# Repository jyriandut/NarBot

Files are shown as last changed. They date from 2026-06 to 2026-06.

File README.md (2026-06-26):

# NarBot

NarBot is an experimental SMARS-style robot workspace. It currently contains
PlatformIO firmware for ESP32 camera/control nodes plus a KiCad PCB project.

The active firmware work is focused on getting reliable ESP32 camera streams,
basic Wi-Fi setup, and simple robot-control building blocks working before
adding a larger autonomous control stack.

## Projects

### `NarbotESP`

Minimal dual-camera firmware for two Seeed Studio XIAO ESP32S3 Sense boards.
The same codebase builds in two modes:

- `main_esp`: starts the `SMARS_MAIN` access point at `192.168.4.1`, serves the
  dashboard, and streams its local camera.
- `front_esp`: joins `SMARS_MAIN` as a station, tries to use static IP
  `192.168.4.10`, and serves its own camera stream.

Main endpoints:

- `http://192.168.4.1/` - dashboard hosted by the main ESP
- `/status` - JSON status
- `/jpg` - single JPEG frame
- `/stream` - MJPEG stream

Default Wi-Fi credentials used by the prototype:

- SSID: `SMARS_MAIN`
- Password: `smars1234`

Build and upload:

```sh
cd NarbotESP
make compile
make upload_main
make upload_front
make monitor
```

Equivalent PlatformIO commands:

```sh
pio run -e main_esp -t upload
pio run -e front_esp -t upload
pio device monitor
```

### `CameraDriver`

Experimental all-in-one XIAO ESP32S3 Sense firmware. This project currently
contains motor-control, camera capture/streaming, setup AP, simple web UI,
serial console, headlight/status LED behavior, and color-sensor code.

Hardware assumptions in the current firmware include:

- Seeed Studio XIAO ESP32S3 Sense with camera
- DFRobot TB6612FNG motor driver
- TCS34725-compatible color sensor at I2C address `0x29`

Setup AP used by the prototype:

- SSID: `CameraDriver-Setup`
- Password: `smars1234`

Build and upload:

```sh
cd CameraDriver
make compile
make upload
make monitor
```

### `NarbotPCB`

KiCad PCB project for the robot electronics.

Commit these files:

- `*.kicad_pro`
- `*.kicad_sch`
- `*.kicad_pcb`

Local KiCad backups and project-local state are ignored by
`NarbotPCB/.gitignore`.

### `ColorCalibration`

Placeholder/calibration workspace. At the moment only generated PlatformIO
output was present, so `.pio/` is ignored there.

## Repository Layout

```text
.
├── CameraDriver/      # Experimental ESP32 camera + motor driver firmware
├── ColorCalibration/  # Calibration workspace
├── NarbotESP/         # Two-ESP camera streaming firmware
├── NarbotPCB/         # KiCad board project
└── README.md
```

## Requirements

- PlatformIO CLI (`pio`)
- USB serial access to the ESP32 boards
- KiCad for the PCB project

The firmware targets ESP32 boards through PlatformIO's `espressif32` platform
and uses the Arduino framework.

## Git Notes

Each project has its own `.gitignore` for generated files. Build output,
downloaded PlatformIO dependencies, clangd caches, notebook scratch files,
macOS metadata, and KiCad backups should stay uncommitted.

Useful status check:

```sh
git status --short --untracked-files=all
```

## Current Milestone

The main firmware milestone is:

1. Main ESP starts the `SMARS_MAIN` access point.
2. Main dashboard opens at `http://192.168.4.1/`.
3. Main ESP camera stream is visible.
4. Front ESP connects to the main AP at `192.168.4.10`.
5. Front ESP stream appears in the main dashboard.

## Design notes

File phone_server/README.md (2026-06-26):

# Phone Server

This module adds the Milestone 2 phone-side communication and control server to the robotics repository.
It provides the middle layer for:

`browser -> Flask server on phone -> ESP32 -> motor`

The phone is expected to run in access point mode and expose a camera stream while the Flask app serves the control UI.

## How It Fits The Repository

`phone_server/` is a self-contained module inside the existing repository. It does not restructure or replace the rest of the project. The other folders such as `analysis`, `bom`, `cad`, `diagrams`, and `docs` remain untouched.

## Folder Structure

```text
phone_server/
|-- app.py
|-- config.py
|-- requirements.txt
|-- README.md
|-- esp32/
|   |-- README.md
|   \-- phone_ap_api_logger/
|       \-- phone_ap_api_logger.ino
|-- services/
|   \-- esp32_client.py
|-- templates/
|   \-- index.html
|-- static/
|   |-- css/
|   |   \-- styles.css
|   \-- js/
|       \-- controls.js
\-- tests/
    \-- test_routes.py
```

## What This Module Does

- Serves a mobile-friendly web page at `/` titled `Sumo Robot Control`
- Embeds the phone camera stream with `<img src="{{ camera_stream_url }}" alt="Camera stream">`
- Sends movement commands from the browser to Flask and then to the ESP32 over HTTP
- Tracks the current connection status, last command, and last speed in memory
- Exposes JSON endpoints for command sending, status checks, and health checks

## Default Network Configuration

The known Milestone 2 defaults are configured in [`config.py`](./config.py):

- Phone AP IP: `192.168.43.1`
- Camera base URL: `http://192.168.43.1:8080`
- Camera stream URL: `http://192.168.43.1:8080/video`
- ESP32 base URL: `http://192.168.43.2`
- ESP32 command endpoint: `/cmd`

## Local Run On A Laptop

From the repository root:

```powershell
python -m venv .venv
.venv\Scripts\Activate.ps1
pip install -r phone_server\requirements.txt
python phone_server\app.py
```

The Flask server listens on:

```text
http://0.0.0.0:5000
```

Open the UI in a browser:

```text
http://127.0.0.1:5000
```

Run the tests:

```powershell
python -m pytest phone_server\tests
```

## Later Run In Termux On The Phone

```sh
pkg update
pkg install python
cd /path/to/sumo-robot-project/phone_server
pip install -r requirements.txt
python app.py
```

When the phone is running in AP mode, connect a browser client to the phone network and open:

```text
http://192.168.43.1:5000
```

The camera stream is expected at:

```text
http://192.168.43.1:8080/video
```

## ESP32 Communication

The reusable ESP32 client lives in [`services/esp32_client.py`](./services/esp32_client.py).
An example ESP32 sketch that joins the phone AP and logs incoming API requests lives in [`esp32/phone_ap_api_logger/phone_ap_api_logger.ino`](./esp32/phone_ap_api_logger/phone_ap_api_logger.ino).

Current request format:

```text
GET /cmd?c=f&s=150
```

Command mapping:

- `FORWARD -> f`
- `BACKWARD -> b`
- `LEFT -> l`
- `RIGHT -> r`
- `STOP -> s`

The request-building logic is separated from the transport call so the project can later switch to POST JSON more easily.

## API Endpoints

### `GET /`

Renders the control page with:

- camera stream
- connection status
- last command
- speed input
- Forward, Backward, Left, Right, Stop buttons

### `POST /api/command`

Request:

```json
{
  "command": "FORWARD",
  "speed": 150
}
```

Successful response example:

```json
{
  "status": "ok",
  "sent_command": "FORWARD",
  "speed": 150,
  "esp32_response": "OK:f",
  "connection_status": "Connected to ESP32"
}
```

### `GET /api/status`

Example response:

```json
{
  "status": "running",
  "phone_ap_ip": "192.168.43.1",
  "camera_stream_url": "http://192.168.43.1:8080/video",
  "esp32_base_url": "http://192.168.43.2",
  "last_command": "STOP",
  "last_speed": 150,
  "connection_status": "Idle",
  "last_error": null
}
```

### `GET /health`

Example response:

```json
{
  "status": "ok"
}
```

## Camera Stream Behavior

The UI keeps working even if the camera stream fails to load. In that case the page shows a fallback message instead of blocking robot controls.

## Known Limitations

- No authentication is included
- No persistent storage or database is used
- The latest state is only kept in memory while the Flask process is running
- The Flask app assumes the ESP32 already exposes `/cmd`
- The camera stream is embedded directly and not proxied through Flask

## Next Steps

- Add hold-to-drive or touch events for smoother robot control
- Add an ESP32 health probe endpoint and display it in `/api/status`
- Add POST JSON support for ESP32 commands if the firmware changes
- Add optional telemetry such as battery level or sensor status

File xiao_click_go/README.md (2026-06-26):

# FrontCam XIAO Firmware

This PlatformIO firmware turns one Seeed Studio XIAO ESP32-S3 Sense into the front-camera, browser UI, and color-sensor board.

Current architecture:

```text
Browser -> FrontCam UI at 192.168.4.1
Browser -> Front camera stream at 192.168.4.1:81/stream
Browser -> QR reader stream at 192.168.4.2:81/stream
Browser -> QR Reader motor API at 192.168.4.2/api/*
FrontCam XIAO -> color sensor over I2C
QR Reader XIAO -> motor driver + distance sensor
```

There is no UART link and no separate motor ESP32 in the current wiring.

## Default Network

FrontCam creates the robot Wi-Fi access point:

```text
SSID: SumoVision
Password: sumo1234
FrontCam IP: 192.168.4.1
```

Open the UI from a laptop or phone connected to `SumoVision`:

```text
http://192.168.4.1
```

The front camera MJPEG stream is:

```text
http://192.168.4.1:81/stream
```

The UI expects the QR Reader XIAO at:

```text
http://192.168.4.2
http://192.168.4.2:81/stream
```

## Connected Hardware

FrontCam board:

```text
XIAO ESP32-S3 Sense camera
Color sensor on I2C
SDA: D4 / GPIO5
SCL: D5 / GPIO6
Default color sensor address: 0x29
```

The color sensor code is written for M5Stack Unit Color / TCS3472-style modules.

## PlatformIO Commands

From this directory:

```powershell
pio run
pio run --target upload
pio device monitor
```

If using the repository virtual environment:

```powershell
..\venv\Scripts\pio.exe run
```

## Click-And-Go Flow

1. Browser opens `http://192.168.4.1`.
2. FrontCam serves the page and front camera stream.
3. Browser click is converted into pixel coordinates.
4. If calibration is enabled, browser applies the homography matrix.
5. Browser sends the movement plan to the QR Reader XIAO:

```text
POST http://192.168.4.2/api/click?... 
```

Without calibration, the browser uses fallback logic:

- left/right image position controls turn direction and turn duration;
- vertical image position controls forward duration;
- center click mostly drives forward.

After camera calibration, enable `CALIBRATION.enabled = true` in the page script and replace the `H` matrix with the measured homography.

## QR Scanner

The browser UI scans QR codes from the second XIAO camera stream.

Current flow:

```text
QR Reader MJPEG stream -> browser canvas -> jsQR decode -> UI result
```

If the `Send QR ID to QR reader board` checkbox is enabled, the browser also sends the detected ID to:

```text
POST http://192.168.4.2/api/qr?id=A1
```

FrontCam also stores the latest local QR result at:

```text
POST http://192.168.4.1/api/qr?id=A1
GET  http://192.168.4.1/api/status
```

Vendored QR decoder:

```text
Library: jsQR 1.4.0
Served as: /jsQR.js
Generated header: include/jsqr_gz.h
License: third_party/jsQR-LICENSE.txt
```

## Useful Endpoints

```text
GET  /                 browser UI
GET  /api/status       FrontCam status, QR reader URL, color sensor reading
GET  /api/color        color sensor reading
POST /api/qr?id=A1     store latest QR ID locally
GET  /capture          single JPEG frame
GET  :81/stream        front camera MJPEG stream
```

## Calibration TODO

Detailed calibration instructions are in [`CALIBRATION.md`](./CALIBRATION.md).

Measure:

- forward speed in `cm/s` at the chosen speed;
- turn speed in `deg/s`;
- homography matrix from front-camera pixel coordinates to ground coordinates.

Then update these constants in `../qr_reader_xiao/src/main.cpp`:

```cpp
TURN_MS_PER_DEG
DRIVE_MS_PER_CM
```

and update the `CALIBRATION.H` matrix in this firmware's HTML script.

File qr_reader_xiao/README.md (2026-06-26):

# QR Reader Robot XIAO Firmware

This firmware turns the second Seeed Studio XIAO ESP32-S3 Sense into the robot-side board.

It handles:

- QR camera stream;
- motor driver control;
- distance sensor reading;
- HTTP API for click-and-go, stop, manual motor commands, QR IDs, and status.

It does not decode QR codes on the ESP32. The FrontCam browser UI loads this stream and decodes QR codes in JavaScript with `jsQR`.

## Role In The Robot

```text
QR Reader XIAO -> joins SumoVision Wi-Fi as 192.168.4.2
QR Reader XIAO -> serves QR camera stream
QR Reader XIAO -> drives the motor driver directly
QR Reader XIAO -> reads the distance sensor over I2C
FrontCam UI -> sends click-and-go HTTP requests to QR Reader XIAO
```

There is no separate motor ESP32 and no UART link in the current wiring.

## Default Network

The QR reader joins the FrontCam access point:

```text
SSID: SumoVision
Password: sumo1234
QR reader IP: 192.168.4.2
Gateway: 192.168.4.1
```

The stream URL expected by `xiao_click_go` is:

```text
http://192.168.4.2:81/stream
```

## Connected Hardware

Default motor driver pins:

```text
DIR1: D0 / GPIO1
PWM1: D1 / GPIO2
PWM2: D2 / GPIO3
DIR2: D3 / GPIO4
```

Default distance sensor pins:

```text
SDA: D4 / GPIO5
SCL: D5 / GPIO6
I2C address: 0x57
```

The distance sensor code is written for M5Stack Unit Sonic-style I2C modules.

If motor direction is reversed, change these constants in `src/main.cpp`:

```cpp
MOTOR1_FORWARD_HIGH
MOTOR2_FORWARD_HIGH
```

If the wiring changes, update:

```cpp
MOTOR_DIR1_PIN
MOTOR_PWM1_PIN
MOTOR_PWM2_PIN
MOTOR_DIR2_PIN
DISTANCE_SDA_PIN
DISTANCE_SCL_PIN
```

## Endpoints

```text
GET  /                         simple status page with camera preview and manual motor buttons
GET  /api/status               JSON status
GET  /api/distance             distance sensor reading
GET  /capture                  single JPEG frame
GET  :81/stream                MJPEG stream
POST /api/click?...            timed click-and-go movement plan
POST /api/command?cmd=f        manual motor command: f,b,l,r,s
POST /api/stop                 immediate stop
POST /api/qr?id=A1             store latest QR ID
```

All API and camera endpoints include CORS headers so the FrontCam UI can call them from `http://192.168.4.1`.

## Build

```powershell
cd C:\Users\finmi\PycharmProjects\sumo-robot-project\qr_reader_xiao
$env:PYTHONUTF8='1'
$env:PYTHONIOENCODING='utf-8'
..\venv\Scripts\pio.exe run
```

Upload, replacing `COMx` with the QR reader XIAO serial port:

```powershell
..\venv\Scripts\pio.exe run --target upload --upload-port COMx
```

## Test

1. Flash and start the FrontCam XIAO first, so `SumoVision` exists.
2. Flash and start the QR Reader XIAO.
3. Connect a laptop or phone to `SumoVision`.
4. Open:

```text
http://192.168.4.2
http://192.168.4.2:81/stream
http://192.168.4.2/api/status
http://192.168.4.2/api/distance
```

5. On `http://192.168.4.2`, test manual buttons with the robot lifted from the table.
6. Open the FrontCam UI at `http://192.168.4.1`.
7. Confirm the QR reader camera appears in the QR panel.
8. Click the front camera image and confirm `/api/status` shows motor phase changes.
9. Show a QR code such as `A1` and confirm `Last QR` updates in the FrontCam UI.

## Safety Notes

- Keep the robot lifted during the first motor direction test.
- Use `POST http://192.168.4.2/api/stop` or the STOP button in the FrontCam UI to stop motors.
- `DISTANCE_AUTO_STOP_ENABLED` is currently `false`; distance is reported but does not automatically stop the robot.

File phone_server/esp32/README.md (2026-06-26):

# ESP32 Phone AP Firmware

This folder contains an Arduino sketch for ESP32 that:

- connects to the phone access point `robonet`
- uses password `12345678qwerty`
- requests a static IP `192.168.43.2`
- exposes an HTTP API compatible with the Flask phone server
- prints every API request to the Serial Monitor

## Sketch

- `phone_ap_api_logger/phone_ap_api_logger.ino`

## Endpoints

- `GET /health`
- `GET /cmd?c=f&s=150`
- `GET /`

## Notes

- The sketch logs request method, URI, client IP, query args, selected headers, and command mapping.
- `/cmd` acknowledges the request with `OK:<code>` so it matches the current Flask client expectations.
- Motor control is not wired in yet; this firmware is focused on connection and API visibility in Serial output.

## Upload

1. Open the `.ino` file in Arduino IDE.
2. Select your ESP32 board.
3. Ensure the ESP32 Arduino core is installed.
4. Upload the sketch.
5. Open Serial Monitor at `115200` baud.

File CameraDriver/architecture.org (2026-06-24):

#+title: SMARS Multi-Camera Robot Architecture

* Overview

#+begin_src d2 :file architecture.png
direction: right

user: "Operator\nbrowser / phone" {
  shape: person
}

robot: "SMARS robot" {
  brain: "Raspberry Pi Zero 2 W\nbrain + web server" {
    ui: "Web UI\ncamera views + click target"
    planner: "Click-to-drive controller\nvisual servo loop"
    camera_proxy: "Camera stream proxy\nsnapshots / MJPEG"
    motor_client: "Motor command client\nshort interruptible pulses"
    safety: "Safety supervisor\nstop + command timeout"
  }

  front_cam: "Front camera node\nAtomS3R-CAM" {
    front_sensor: "GC0308\nforward view"
    front_api: "/snapshot.jpg or /stream.mjpg"
  }

  up_cam: "Upward camera node\nAtomS3R-CAM" {
    up_sensor: "GC0308\nceiling / marker view"
    up_api: "/snapshot.jpg or /stream.mjpg"
  }

  bottom_sensor: "Bottom-facing sensor\nchoose one" {
    ir: "IR reflectance\nline / floor edge"
    flow: "Optical flow\nmotion over floor"
    bottom_cam: "IR / NoIR camera\nfloor image"
  }

  motor_node: "Motor node\nAtom / ESP32 / AtomS3R-CAM" {
    motor_api: "Motor API\nleft/right speed + duration"
    firmware_safety: "Firmware safety\nstop on boot + timeout"
    driver: "L298N motor driver"
    motors: "2 x G12-N20 DC motors"
  }
}

power: "Power system" {
  logic_power: "5V logic rail\nPi + camera nodes"
  motor_power: "Motor battery\nL298N VMOT"
  common_ground: "Shared ground"
}

user -> robot.brain.ui: "HTTP/WebSocket"

robot.brain.ui -> robot.brain.planner: "clicked image point\nx,y + frame size"
robot.brain.camera_proxy -> robot.front_cam.front_api: "fetch front frames\nWi-Fi HTTP"
robot.brain.camera_proxy -> robot.up_cam.up_api: "fetch upward frames\nWi-Fi HTTP"
robot.brain.planner -> robot.brain.motor_client: "turn / forward intent"
robot.brain.safety -> robot.brain.motor_client: "stop override"
robot.brain.motor_client -> robot.motor_node.motor_api: "POST motor pulse\nleft,right,duration_ms"

robot.front_cam.front_sensor -> robot.front_cam.front_api: "RGB565 -> JPEG/MJPEG"
robot.up_cam.up_sensor -> robot.up_cam.up_api: "RGB565 -> JPEG/MJPEG"

robot.bottom_sensor.ir -> robot.brain.planner: "floor reflectance"
robot.bottom_sensor.flow -> robot.brain.planner: "delta x/y"
robot.bottom_sensor.bottom_cam -> robot.brain.camera_proxy: "bottom image"

robot.motor_node.motor_api -> robot.motor_node.firmware_safety
robot.motor_node.firmware_safety -> robot.motor_node.driver
robot.motor_node.driver -> robot.motor_node.motors

power.logic_power -> robot.brain
power.logic_power -> robot.front_cam
power.logic_power -> robot.up_cam
power.logic_power -> robot.motor_node
power.motor_power -> robot.motor_node.driver
power.common_ground -> robot.brain
power.common_ground -> robot.front_cam
power.common_ground -> robot.up_cam
power.common_ground -> robot.motor_node

robot.brain.planner -> robot.brain.planner: "V1 loop:\n1. click target\n2. center target horizontally\n3. drive short pulse\n4. refresh frame\n5. repeat or stop"
#+end_src

#+RESULTS:
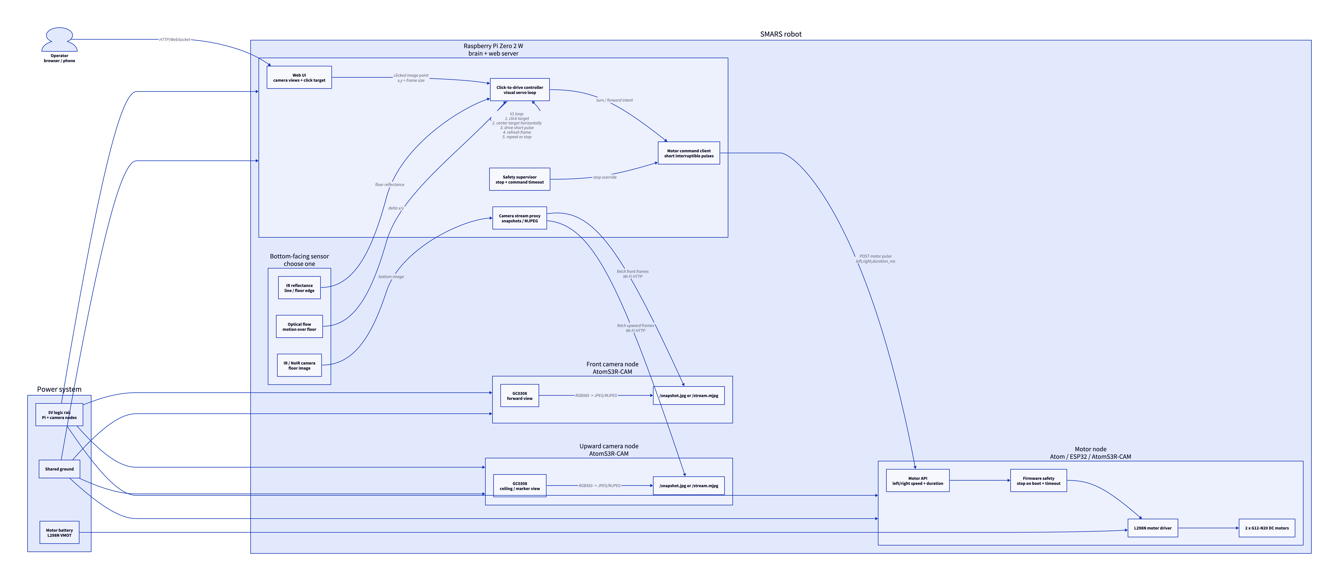
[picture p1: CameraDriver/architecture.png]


* Notes

- The Raspberry Pi is the coordinator because it can host the web UI, combine several camera feeds, and run navigation logic without crowding the ESP32 boards.
- The motor node should only accept short, timed commands. Long autonomous movement belongs in the Pi controller, where camera feedback and stop handling are available.
- The first click-to-drive version should treat a click as a bearing in the front camera image, not as a precise world coordinate.
- The bottom-facing requirement should start with IR reflectance or optical flow unless actual floor images are needed.
- Every moving layer needs a stop path: browser stop button, Pi safety supervisor, motor-node timeout, and stop-on-boot firmware behavior.

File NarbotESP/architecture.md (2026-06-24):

Create a minimal PlatformIO Arduino C++ project for a two-ESP32 robot camera setup.

Hardware:
- Both boards are Seeed Studio XIAO ESP32S3 Sense boards with camera modules.
- Use PlatformIO with framework = arduino.
- Use board = seeed_xiao_esp32s3.
- Use Serial logging at 115200 baud.

Goal:
Set up one codebase that can be built in two modes:
1. MAIN_ESP
2. FRONT_ESP

Use build flags in platformio.ini:
- env:main_esp with -D MAIN_ESP
- env:front_esp with -D FRONT_ESP

Do not overcomplicate the project yet. Avoid FreeRTOS task architecture for now unless absolutely necessary. Use simple Arduino setup/loop plus non-blocking style where possible. The goal is to get Wi-Fi, web server, camera streaming, and logs working first.

Required files:
- platformio.ini
- src/main.cpp
- src/config.h
- src/camera_pins.h
- src/camera_setup.h / .cpp
- src/web_server.h / .cpp
- src/wifi_setup.h / .cpp

Functionality:

MAIN_ESP mode:
- Start Wi-Fi Access Point.
- AP SSID: "SMARS_MAIN"
- AP password: "smars1234"
- Use AP IP 192.168.4.1.
- Start a web server on port 80.
- Initialize the local XIAO ESP32S3 Sense camera.
- Expose endpoints:
  - GET /              -> main HTML dashboard
  - GET /status        -> plain text or JSON status
  - GET /jpg           -> one JPEG frame from main ESP camera
  - GET /stream        -> MJPEG stream from main ESP camera
- The dashboard page should show:
  - Title: "SMARS Robot Dashboard"
  - Main ESP camera feed using 
  - Front ESP camera feed using 
  - Basic status text
- Log to Serial:
  - boot mode
  - Wi-Fi AP started
  - AP IP address
  - camera init success/failure
  - web server started
  - every incoming request path if easy to do

FRONT_ESP mode:
- Connect to the MAIN_ESP access point as Wi-Fi station.
- SSID: "SMARS_MAIN"
- password: "smars1234"
- Try to use static IP 192.168.4.2, gateway 192.168.4.1, subnet 255.255.255.0.
- Start a web server on port 80.
- Initialize the local XIAO ESP32S3 Sense camera.
- Expose endpoints:
  - GET /status        -> plain text or JSON status
  - GET /jpg           -> one JPEG frame
  - GET /stream        -> MJPEG stream
- Log to Serial:
  - boot mode
  - Wi-Fi connection attempts
  - assigned IP
  - camera init success/failure
  - web server started
  - every incoming request path if easy to do

Camera requirements:
- Use esp_camera.h.
- Configure the camera for Seeed Studio XIAO ESP32S3 Sense.
- Use PSRAM if available.
- Start with low resolution for reliability:
  - frame_size = FRAMESIZE_QVGA
  - jpeg_quality around 12
  - fb_count = 1 or 2 depending on PSRAM
- Include clear comments where the XIAO ESP32S3 Sense camera pin mapping is defined.
- If exact pin mapping is uncertain, make it isolated in camera_pins.h and add a comment saying it must match the Seeed XIAO ESP32S3 Sense camera example.

Web server:
- Prefer the standard ESP32 Arduino WebServer library for simplicity.
- Implement a basic MJPEG stream endpoint similar to common ESP32 CameraWebServer examples.
- Keep the code readable and beginner-friendly.
- Avoid async web server libraries for the first version.
- Avoid websockets for now.
- Avoid OTA for now.
- Avoid motor code for now.
- Avoid QR code and color detection for now.

Code quality:
- Split code into small files but do not over-engineer.
- Use functions like:
  - setupWifi()
  - setupCamera()
  - setupWebServer()
  - handleWebServer()
  - logBootInfo()
- Use #ifdef MAIN_ESP and #ifdef FRONT_ESP where needed.
- Make it compile in PlatformIO.
- Include comments explaining how to build and upload each environment:
  - pio run -e main_esp -t upload
  - pio run -e front_esp -t upload
  - pio device monitor

Important:
- Do not create a complex robotics framework yet.
- Do not add FreeRTOS tasks yet.
- Do not add motor control yet.
- Do not add QR decoding yet.
- First milestone is:
  1. Main ESP starts AP.
  2. Main ESP dashboard opens at http://192.168.4.1/
  3. Main ESP camera stream is visible.
  4. Front ESP connects to AP.
  5. Front ESP stream is visible from the main dashboard.

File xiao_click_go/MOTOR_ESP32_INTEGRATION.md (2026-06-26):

# Two-XIAO HTTP Integration Guide

This document describes the current robot wiring and firmware split.

There is no separate motor ESP32 in the current architecture. The motor driver is connected directly to the `QR Reader XIAO`, and the two XIAO boards do not communicate over UART.

## System Architecture

```text
Browser <--Wi-Fi--> FrontCam XIAO ESP32-S3 Sense
Browser <--Wi-Fi--> QR Reader XIAO ESP32-S3 Sense

FrontCam XIAO:
  - creates SumoVision Wi-Fi
  - serves browser UI
  - serves front camera stream
  - reads color sensor

QR Reader XIAO:
  - joins SumoVision as 192.168.4.2
  - serves QR camera stream
  - receives HTTP movement commands
  - drives motor driver pins directly
  - reads distance sensor
```

The browser is the bridge between the two boards:

```text
click on front stream -> browser computes movement plan -> POST http://192.168.4.2/api/click
QR stream frame -> browser jsQR decode -> optional POST http://192.168.4.2/api/qr
```

## Wi-Fi Layout

FrontCam access point:

```text
SSID: SumoVision
Password: sumo1234
FrontCam IP: 192.168.4.1
FrontCam stream: http://192.168.4.1:81/stream
```

QR Reader station:

```text
QR Reader IP: 192.168.4.2
Gateway: 192.168.4.1
QR stream: http://192.168.4.2:81/stream
Robot API: http://192.168.4.2/api/status
```

The laptop or phone must be connected to `SumoVision`.

## Wiring Summary

### FrontCam XIAO

```text
XIAO ESP32-S3 Sense camera
Color sensor:
  SDA -> D4 / GPIO5
  SCL -> D5 / GPIO6
  VCC -> 3.3 V or module-supported VCC
  GND -> GND
```

Default color sensor address:

```text
0x29
```

### QR Reader XIAO

```text
XIAO ESP32-S3 Sense camera
Distance sensor:
  SDA -> D4 / GPIO5
  SCL -> D5 / GPIO6
  VCC -> module-supported VCC
  GND -> GND
```

Default distance sensor address:

```text
0x57
```

Default motor driver pins:

```text
DIR1 -> D0 / GPIO1
PWM1 -> D1 / GPIO2
PWM2 -> D2 / GPIO3
DIR2 -> D3 / GPIO4
GND  -> common GND
VCC  -> logic supply
VM   -> motor supply from step-down converter
```

If motor direction is reversed, change these constants in `qr_reader_xiao/src/main.cpp`:

```cpp
MOTOR1_FORWARD_HIGH
MOTOR2_FORWARD_HIGH
```

If the breadboard wiring changes, update:

```cpp
MOTOR_DIR1_PIN
MOTOR_PWM1_PIN
MOTOR_PWM2_PIN
MOTOR_DIR2_PIN
DISTANCE_SDA_PIN
DISTANCE_SCL_PIN
COLOR_SDA_PIN
COLOR_SCL_PIN
```

## HTTP API

### Movement From Browser To QR Reader

Click-and-go request:

```text
POST http://192.168.4.2/api/click?turn_dir=1&turn_ms=400&drive_ms=900&speed=150
```

Calibrated request:

```text
POST http://192.168.4.2/api/click?angle=25.0&distance=40.0&speed=150
```

The QR Reader turns these into timed motor states:

```text
turn left/right
stop briefly
drive forward
stop
```

Manual motor command:

```text
POST http://192.168.4.2/api/command?cmd=f&speed=130
```

Command codes:

| Code | Meaning |
| --- | --- |
| `f` | forward |
| `b` | backward |
| `l` | turn left |
| `r` | turn right |
| `s` | stop |

Emergency stop:

```text
POST http://192.168.4.2/api/stop
```

### QR ID

The browser stores every detected QR ID locally on FrontCam:

```text
POST http://192.168.4.1/api/qr?id=A1
```

If the UI checkbox is enabled, the browser also sends it to the robot-side board:

```text
POST http://192.168.4.2/api/qr?id=A1
```

The QR Reader stores the latest ID in `/api/status`. It does not automatically move from a QR message.

### Sensors

FrontCam color sensor:

```text
GET http://192.168.4.1/api/color
```

QR Reader distance sensor:

```text
GET http://192.168.4.2/api/distance
```

Combined status:

```text
GET http://192.168.4.1/api/status
GET http://192.168.4.2/api/status
```

## Integration Test Sequence

### 1. Flash FrontCam XIAO

```powershell
cd C:\Users\finmi\PycharmProjects\sumo-robot-project\xiao_click_go
..\venv\Scripts\pio.exe run --target upload --upload-port COMx
```

Expected serial output:

```text
Starting FrontCam XIAO
FrontCam AP SSID: SumoVision
FrontCam AP IP: 192.168.4.1
FrontCam UI ready on port 80
Front camera stream ready on port 81
```

Open:

```text
http://192.168.4.1
http://192.168.4.1/api/color
```

### 2. Flash QR Reader XIAO

```powershell
cd C:\Users\finmi\PycharmProjects\sumo-robot-project\qr_reader_xiao
..\venv\Scripts\pio.exe run --target upload --upload-port COMx
```

Expected serial output:

```text
Starting QR Reader Robot XIAO
Connecting QR reader to SSID: SumoVision
QR reader IP: 192.168.4.2
QR reader robot API ready on port 80
QR stream ready on port 81
```

Open:

```text
http://192.168.4.2
http://192.168.4.2/api/status
http://192.168.4.2/api/distance
http://192.168.4.2:81/stream
```

### 3. Test Motors Safely

Lift the robot so wheels cannot drive away.

Open:

```text
http://192.168.4.2
```

Use the manual motor buttons. If direction is wrong, change `MOTOR1_FORWARD_HIGH` or `MOTOR2_FORWARD_HIGH`.

### 4. Test Click-And-Go

Open:

```text
http://192.168.4.1
```

Click the front camera image.

Expected:

- FrontCam UI shows the clicked pixel and fallback or calibrated movement plan.
- Browser sends `/api/click` to `192.168.4.2`.
- QR Reader `/api/status` shows `motor.phase`, `turn_ms`, `drive_ms`, and `last_command`.
- Motors turn, stop briefly, drive forward, then stop.

### 5. Test QR

Open FrontCam UI:

```text
http://192.168.4.1
```

Show QR code `A1` to the QR reader camera.

Expected:

- `Last QR` updates in the FrontCam UI.
- If the checkbox is enabled, `http://192.168.4.2/api/status` shows `"last_qr_id":"A1"`.

## Troubleshooting

| Symptom | Likely Cause | Fix |
| --- | --- | --- |
| QR Reader does not appear at `192.168.4.2` | FrontCam AP is off, wrong SSID/password, or QR Reader booted first and has not reconnected yet | Start FrontCam first, then reset QR Reader |
| QR stream loads but QR decode fails | QR too small, blurred, bad lighting, or QR stream not visible in browser canvas | Move QR closer, improve lighting, check browser console |
| Clicks do not move robot | QR Reader is offline or `/api/click` blocked | Check `http://192.168.4.2/api/status` from the same browser |
| Motors do not move from manual buttons | Motor power missing, driver wiring wrong, or wrong pins | Check VM motor supply, GND, and pin constants |
| Robot moves backward when asked forward | Motor direction polarity is inverted | Change `MOTOR1_FORWARD_HIGH` or `MOTOR2_FORWARD_HIGH` |
| Distance reads offline | Wrong I2C pins, power, address, or sensor model | Check D4/D5 wiring and sensor address |
| Color reads offline | Wrong I2C pins, power, address, or sensor model | Check FrontCam D4/D5 wiring and sensor address |

## Final Checklist

- [ ] FrontCam XIAO UI loads at `http://192.168.4.1`
- [ ] Front camera stream works at `http://192.168.4.1:81/stream`
- [ ] Color sensor responds at `http://192.168.4.1/api/color`
- [ ] QR Reader joins `SumoVision` as `192.168.4.2`
- [ ] QR camera stream works at `http://192.168.4.2:81/stream`
- [ ] Distance sensor responds at `http://192.168.4.2/api/distance`
- [ ] Manual motor buttons work with robot lifted
- [ ] STOP button stops motors
- [ ] FrontCam UI shows both camera streams
- [ ] Click on front stream sends `/api/click` to QR Reader
- [ ] QR detection updates UI
- [ ] Optional QR forwarding updates QR Reader `/api/status`
- [ ] Robot still needs field calibration for real movement accuracy

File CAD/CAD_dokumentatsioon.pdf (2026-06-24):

Mehaanika ja 3D-printimise Dokumentatsioon (NarBot)

### 1. Šassii mehaaniline kontseptsioon ja disain (Fusion 360)

- Üldvaade: Robotil on kompaktne, suletud tüüpi šassii, mis kaitseb sisemist elektroonikat ja juhtmeid sumomaadluse kokkupõrgete eest.
- Ajamisüsteem: Robot on kaherattaveoline. Nakke maapinnaga toimub läbi roomikute. Valisime selle versiooni, kuna see oli erivev teistest gruppidest, kes kasutasid põhiliselt rattaid, et saada võrdlusmomenti ja võistlusolukorras ära katsetada, kumb on siis parem variant, kas rattad või roomik. SMARS robotide puhul kasutatakse ka millegipärast palju roomikuid, mis oli siis inspiratsiooniks (Joonis 1).

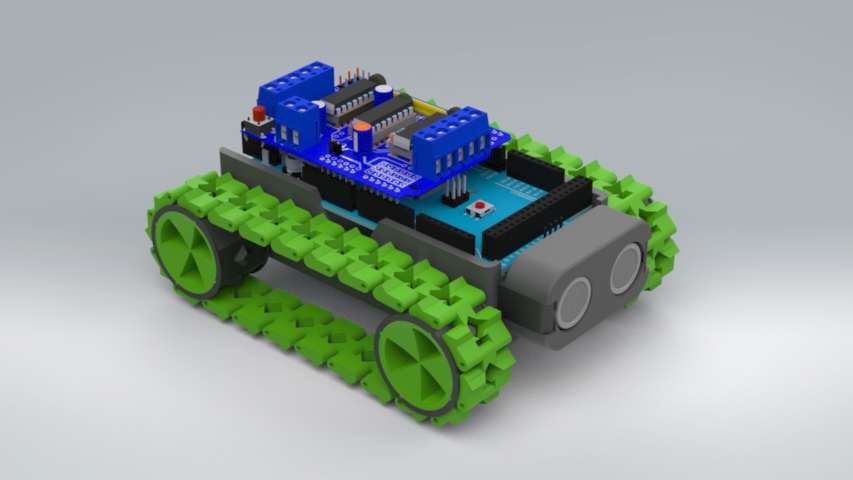
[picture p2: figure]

Joonis 1. SMARS roomikutega robot inspiratsiooniks

- Kaalujaotus ja kliirens: Kuna kere põhjas on värviandur (Joonis 2), siis ei saanud akut väga madalale panna, et oleks madal raskuskese ja stabiilsus kokkupõrgetel teiste robotitega. Kuna ruumi pidi jätma ka juhtmetele, siis pidime panema akupanaga kõrgemale, kui esialgses plaanis (Joonis 3).

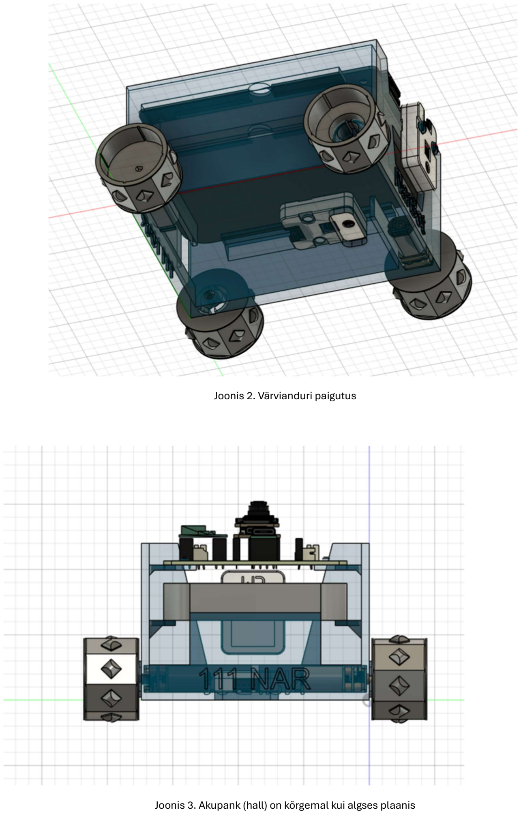
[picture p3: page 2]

Joonis 2. Värvianduri paigutus

Joonis 3. Akupank (hall) on kõrgemal kui algses plaanis

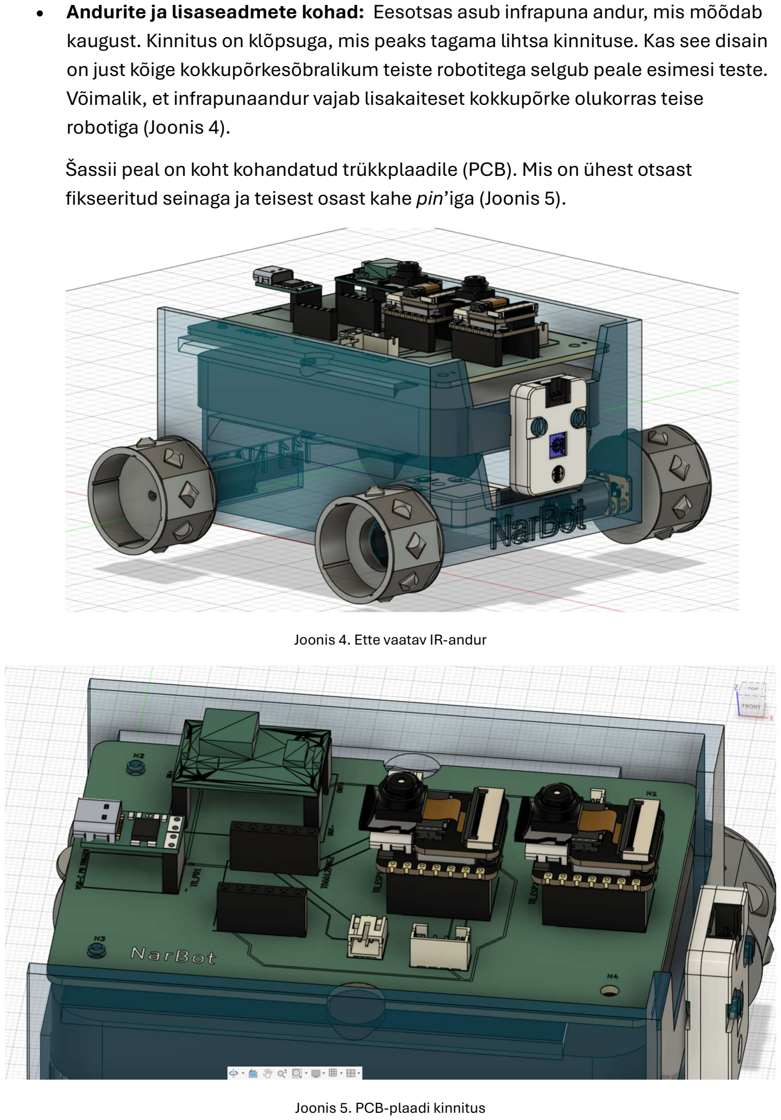
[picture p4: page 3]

- Andurite ja lisaseadmete kohad: Eesotsas asub infrapuna andur, mis mõõdab kaugust. Kinnitus on klõpsuga, mis peaks tagama lihtsa kinnituse. Kas see disain on just kõige kokkupõrkesõbralikum teiste robotitega selgub peale esimesi teste. Võimalik, et infrapunaandur vajab lisakaiteset kokkupõrke olukorras teise robotiga (Joonis 4).
Šassii peal on koht kohandatud trükkplaadile (PCB). Mis on ühest otsast fikseeritud seinaga ja teisest osast kahe pin’iga (Joonis 5).

Joonis 4. Ette vaatav IR-andur

Joonis 5. PCB-plaadi kinnitus

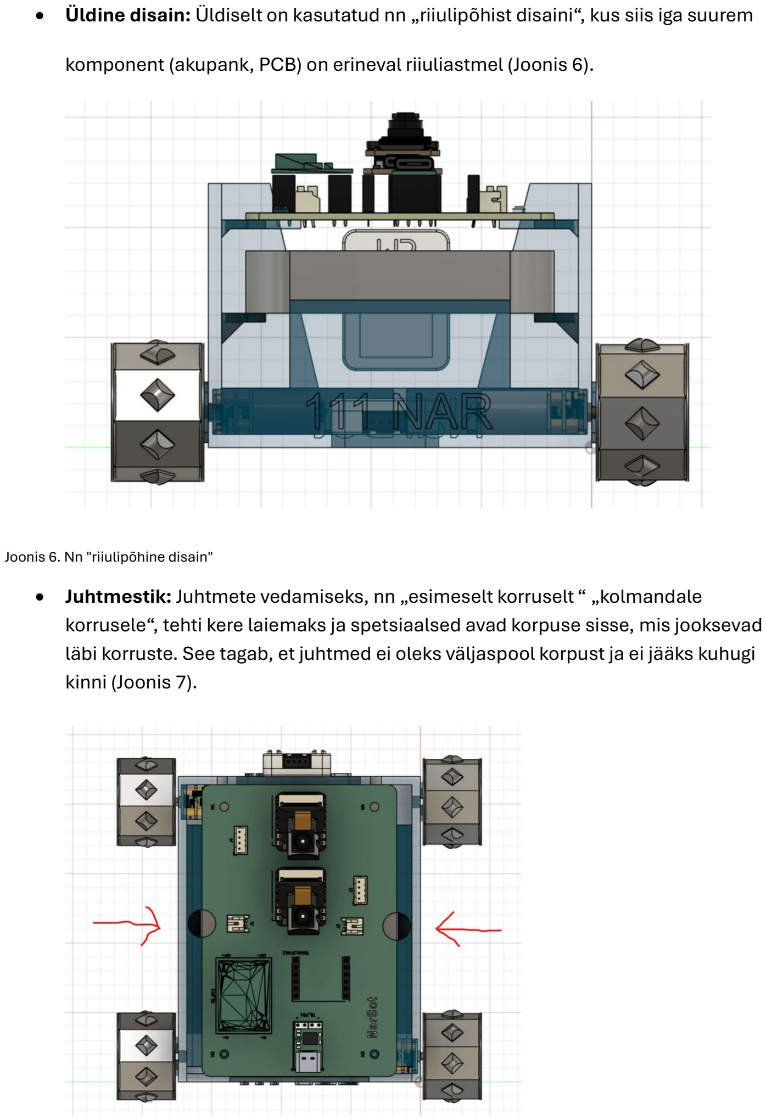
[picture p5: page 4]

- Üldine disain: Üldiselt on kasutatud nn „riiulipõhist disaini“, kus siis iga suurem

komponent (akupank, PCB) on erineval riiuliastmel (Joonis 6).

Joonis 6. Nn "riiulipõhine disain"
- Juhtmestik: Juhtmete vedamiseks, nn „esimeselt korruselt “ „kolmandale korrusele“, tehti kere laiemaks ja spetsiaalsed avad korpuse sisse, mis jooksevad läbi korruste. See tagab, et juhtmed ei oleks väljaspool korpust ja ei jääks kuhugi kinni (Joonis 7).

Joonis 7. Avad juhtmete jaoks
2. 3D-printimise spetsifikatsioon
Detailid oli plaanis välja printida kasutades järgnevaid Prusa Sliceri settinguid (Joonis 8), kus kerel oli ümber brim, et nurgad üles ei tuleks. Kuna kerele tehti 2 cutout’i (Joonis 9), et mootorid oleksid rohkem väljapool ja et ratta võll oleks rattaga rohkem kontaktis, siis tekkis probleem, et nurgad olid ülespoole kaardus (Joonis 10) ja mootrit ei olnudki võimalik paigaldada. Et seda vältida oli plaanis kasutada tugevat 10 mm brim’i, et kere nurgad ülesse ei tuleks. Infill’iks valiti 15%, et seinad oleksid natuke tugevamad ja peaksid näiteks vastu momendile, mida mootor kannab edasi ratastele.
Kuid kuna ülikool oli kinni, siis kasutati Narvas olevat printimisfirmat (Joonis 11).

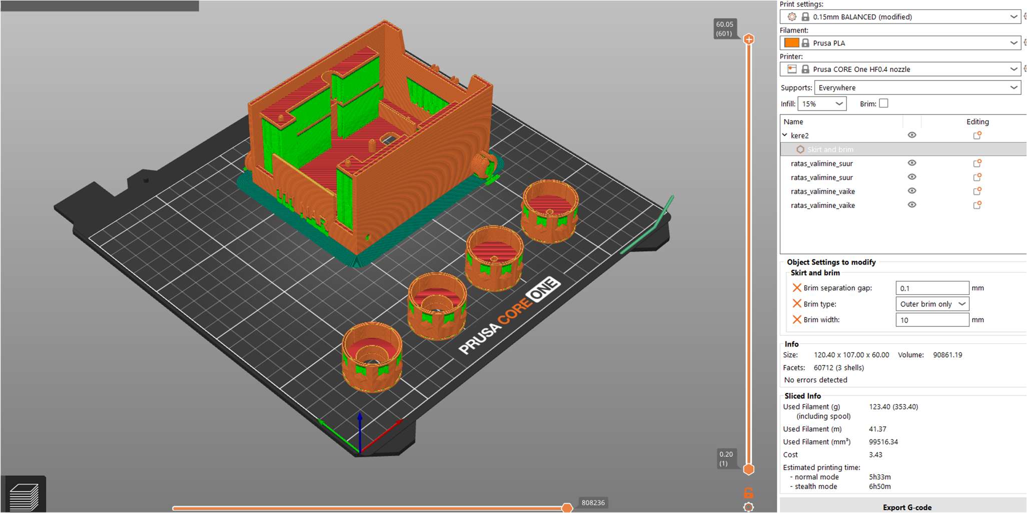
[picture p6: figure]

Joonis 8. Prusa Sliceri settingud

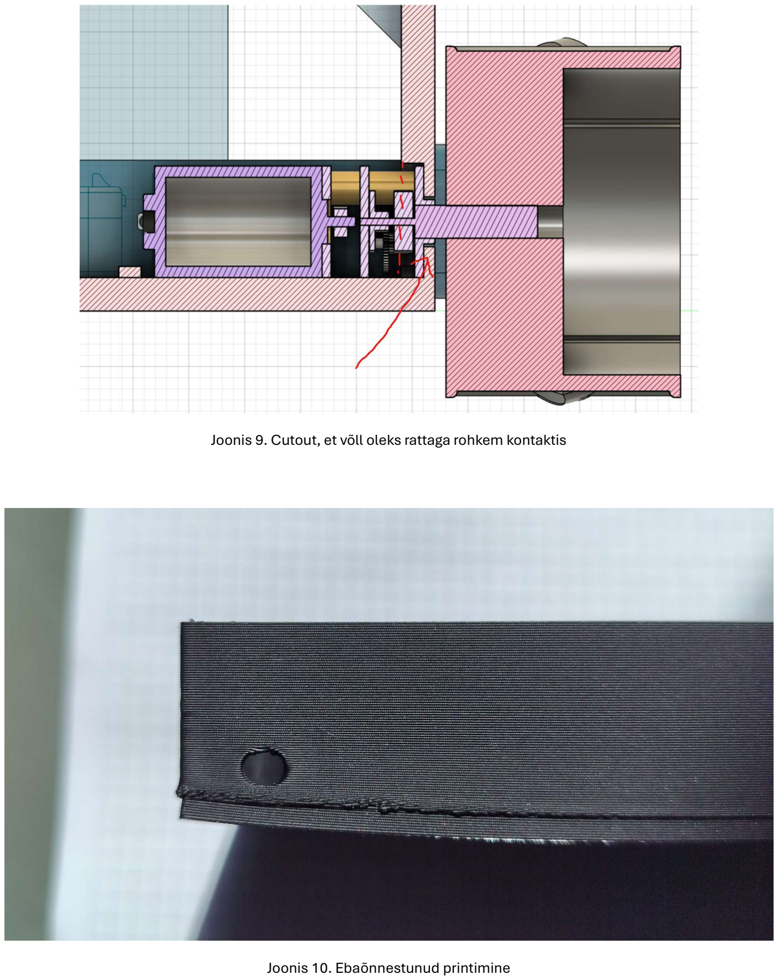
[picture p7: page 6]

Joonis 9. Cutout, et võll oleks rattaga rohkem kontaktis

Joonis 10. Ebaõnnestunud printimine

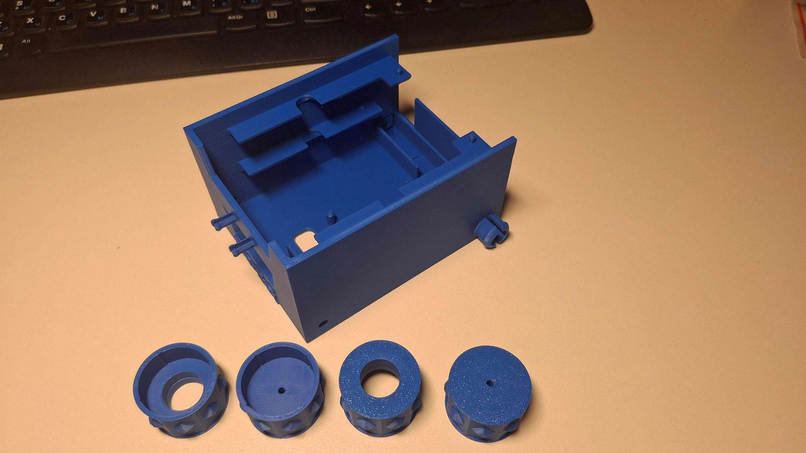
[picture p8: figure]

Joonis 11. Lõplik tulemus

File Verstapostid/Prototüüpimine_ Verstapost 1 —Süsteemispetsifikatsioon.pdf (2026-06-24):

# SUMOROBOT – Verstapost 1 Süsteemispetsifikatsioon

## 1. Projekti ülevaade

Projekti eesmärk

Projekti eesmärk on arendada SMARS-inspireeritud roomikutega sumorobot, mis osaleb Narva Kolledži robotiareenil toimuvatel sumovõistlustel. Robot peab olema juhitav Android telefonist, suutma tuvastada vastaseid, mõõta kaugust takistusteni, tuvastada areeni piire ning määrata oma asukohta QR-koodide abil.

Robot on projekteeritud kasutades võimalikult palju olemasolevaid ja taaskasutatud komponente, et vähendada süsteemi maksumust ja lihtsustada tootmist.

Süsteemi piirid

Süsteemi kuuluvad:

Roomikšassii
Mootorid ja mootoridraiver
ESP32-S3 juhtkontroller
Esikaamera
Üles suunatud kaamera QR-positsioneerimiseks Kaugusandur
Värviandur
Android rakendus
USB OTG sidekanal

Süsteemi ei kuulu:

Võistlusareen
Operaatori telefon
WiFi infrastruktuur
Kasutajad

Võistluse operaator
Arendustiim
Korraldajad

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
# 2. Funktsionaalsed nõuded

## MUST

FN-001

Robot peab liikuma edasi, tagasi, vasakule ja paremale Android rakenduse käskude alusel.

FN-002

Robot peab kuvama reaalajas videopildi operaatori telefonis.

FN-003

Robot peab mõõtma kaugust ees olevate objektideni vähemalt 50 mm kuni 1200 mm ulatuses.

FN-004

Robot peab tuvastama enda all oleva pinna värvi.

FN-005

Robot peab tuvastama areeni piiri värvi ja peatama väljasõidu.

FN-006

Robot peab suutma pöörata kohapeal mootoreid vastassuunas juhtides.

FN-007

Robot peab lugema laest QR-koode.

FN-008

Robot peab määrama oma ligikaudse asukoha QR-koodide koordinaatide alusel.

FN-009

Robot peab töötama akupangast vähemalt 30 minutit.

FN-010

Robot peab suutma jätkata tööd pärast WiFi ühenduse lühiajalist katkemist.

## SHOULD

FN-011

Robot peaks suutma autonoomselt vastast jälitada.

FN-012

Robot peaks kuvama kaardi enda asukohaga.

FN-013

Robot peaks logima telemeetriaandmeid.

## COULD

FN-014

Operaator võiks puudutada videopilti ning robot võiks sõita valitud punktini.

FN-015

Robot võiks kasutada QR-positsioneerimist täielikult autonoomseks navigeerimiseks.

# 3. Jõudluseesmärgid

Parameeter | Eesmärk | Minimaalne | Mõõtmismeetod
Maksimaalne kiirus | 0.8 m/s | 0.4 m/s | 3 m sõidutest
Pööramiskiirus | 180°/s | 90°/s | Videoanalüüs
Aku tööaeg | 60 min | 30 min | Täiskoormuse test
Kaamera FPS | 25 FPS | 15 FPS | Rakenduse statistika
Video latentsus | <150 ms | <300 ms | Võrgu mõõtmine
QR lugemiskaugus | 1.5 m | 1.0 m | Test QR märgiga
Positsioneerimise viga | <10 cm | <25 cm | Mõõdistatud areen
ToF mõõteviga | <3 cm | <5 cm | Kontrollmõõtmine
Värvituvastus | 95% | 80% | 100 mõõtmist

# 4. Referentssüsteemid

## Referentssüsteem 1 – SMARS

Eelised:

Lihtne konstruktsioon
3D-prinditav
Odav

•
•
•

Puudused:

Puudub positsioneerimine
Puudub videovoog

## Referentssüsteem 2 – mecArena robot

Eelised:

Võistlusvalmis
Standardiseeritud areen

Puudused:

Piiratud autonoomsus

## Referentssüsteem 3 – ESP32-CAM robot

Eelised:

Odav videolahendus
Lihtne integreerida

Puudused:

Piiratud arvutusvõimsus

# 5. Komponentide valik ja põhjendus

## Juhtkontroller

Valik

Seeed Studio XIAO ESP32-S3

Põhjendus

WiFi
Bluetooth
USB OTG tugi
Väike mõõt
Alternatiivid

Arduino Nano
Raspberry Pi Pico W

Valiti ESP32-S3 suurema jõudluse tõttu.

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
## Mootorid

Valik

N20 metallreduktoriga mootorid

Reduktsioon:

1:50
1:120
Otsus

Esimene prototüüp kasutab 1:50 reduktorit suurema kiiruse saavutamiseks.

## Mootoridraiver

Valik

TB6612FNG

Põhjendus

Efektiivsem kui L298N
Väiksem energiakadu
Piisav vool N20 mootoritele

## Kaugusandur

Valik

VL53L0X

Põhjendus

I2C liides
Kompaktne
50 mm kuni 1200 mm mõõtevahemik

## Esikaamera

Valik

Acebott ESP32-CAM

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
Funktsioon

Vastaste tuvastamine
Videoedastus

## Ülesvaatav kaamera

Valik

QA011 ESP32-CAM

Funktsioon

QR lugemine
Positsioneerimine

## Toitesüsteem

Valik

USB-C PD Trigger + Powerbank

Põhjendus

Powerbank → 12 V → mootorid

Powerbank → DFR1015 → 5 V → ESP32 ja kaamerad

# 6. Mehhaaniline kontseptsioon

## Šassii

Tüüp:

SMARS inspireeritud

Materjal:

PLA+
PETG

Mõõtmed:

Pikkus 180 mm
Laius 140 mm
Kõrgus 90 mm

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
Mass:

Eesmärk 1.0–1.5 kg

## Roomikud

3D-prinditud lülid
TPU sisetallad

## Kaalujaotus

60% massist ees
parem tõukejõud sumovõistluses

# 7. Elektriline arhitektuur

Powerbank ↓ USB-C PD Trigger ↓ 12V siin ↓ TB6612 ↓ N20 mootorid

Powerbank ↓ DFR1015 ↓ 5V siin ↓ ESP32-S3 ↓ VL53L0X ↓ ESP32-CAM (ees) ↓ ESP32-CAM (üles)

# 8. Tarkvaraarhitektuur

## Android rakendus

Moodulid:

Juhtpaneel
Videovaade
Telemeetria
Seadistused

## ESP32 püsivara

Moodulid:

Mootorijuhtimine
Andurite lugemine
Sideprotokoll
Diagnostika

## Sideprotokoll

USB OTG Serial

Käsud:

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
FWD BACK LEFT RIGHT STOP

Andmed:

DIST=xxx COLOR=x BAT=x

# 9. Riskianalüüs

Risk | Mõju | Tõenäosus | Leevendus
Roomikute purunemine | Kõrge | Keskmine | Varuosad
Aku ülekoormus | Kõrge | Madal | Kaitse ja testid
QR lugemine ebaõnnestub | Keskmine | Kõrge | Varualgoritm
WiFi viivitus | Keskmine | Keskmine | USB OTG juhtimine
Mootorite ülekuumenemine | Keskmine | Madal | Temperatuuritest

# 10. Teostatavusanalüüs

## Analüüs 1 – Mootori pöördemoment

Roboti mass: 1.5 kg

Hõõrdetegur: 0.7

Vajalik jõud:

F = m × g × μ

F = 1.5 × 9.81 × 0.7

F = 10.3 N

Rataste efektiivne raadius: 20 mm

Vajalik moment:

T = F × r

T = 10.3 × 0.02

T = 0.206 Nm

Kahe mootori korral:

0.103 Nm mootorile

N20 1:50 reduktoriga mootor saavutab ligikaudu 0.12–0.18 Nm.

Järeldus: Mootorid on piisavad.

# 11. Testimisplaan

FN-001: Sõidutest 3 m rajal.

FN-003: Mõõta kaugusi 0.1 m kuni 1.2 m.

FN-004: Testida vähemalt 3 erinevat värvi.

FN-007: Lugeda 20 QR-koodi erinevatelt kaugustelt.

FN-009: Täiskoormusel aku kestvuse mõõtmine.

# 12. Arendusgraafik

## Verstapost 2

Šassii CAD
Elektroonika prototüüp
Mootoritestid

## Verstapost 3

Android rakendus
Videovoog
Andurite integratsioon

## Verstapost 4

QR positsioneerimine
Autonoomsed funktsioonid

## Verstapost 5

Võistlustestid
Optimeerimine
Dokumentatsiooni lõpetamine

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
# 13. Esimese prototüübi ostunimekiri

Komponent | Kogus
N20 1:50 mootor | 2
TB6612FNG | 1
VL53L0X | 1
ESP32-S3 XIAO | 1
ESP32-CAM | 2
USB-C PD Trigger | 1
DFR1015 | 1
Roomikud | 2
Laagrid | 8
Kruvid M3 | 50
Powerbank | 1
PLA+ filament | 1 kg

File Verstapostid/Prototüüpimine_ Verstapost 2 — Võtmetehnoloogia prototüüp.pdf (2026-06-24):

# SUMOROBOT

## Verstapost 2 – Võtmetehnoloogia prototüüp

# 1. Projekti eesmärk

Verstapost 2 eesmärk on valideerida kõik Sumoroboti kriitilised tehnoloogiad enne lõpliku roboti ehitamist.

Selles etapis ei hinnata lõplikku disaini, vaid kontrollitakse, kas põhilised alamsüsteemid töötavad:

roomikajam
mootorijuhtimine
WiFi side
veebiliides
videopilt
andurite liidestamine

Prototüüp peab tõestama, et tulevase roboti põhifunktsioonid on tehniliselt teostatavad.

# 2. Hetkeseis

Valmis on järgmised süsteemi osad:

## Mehhaanika

Valmis on 3D-prinditud testšassii.

Šassii on ehitatud SMARS kontseptsiooni põhjal ning kasutab kahte roomikut.

Roomikud on samuti 3D-prinditud.

Roomiku lülid on ühendatud plastmassist traadiga, mille otsad on termiliselt sulatatud, et vältida ühenduste lahtitulekut.

Valmis komponendid

testplatvorm
roomikud
mootorikinnitused
Siia vaja lisada

CAD mudeli pildid

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
šassii mõõtmed
šassii mass
roomiku lülide arv

# 3. Elektriline arhitektuur

## Kasutatavad komponendid

Komponent | Funktsioon
Seeed Studio XIAO ESP32-S3 | põhikontroller
TB6612FNG | mootoridraiver
2 × N20 reduktormootor | liikumine
USB-C PD Trigger | 12 V mootoritoide
Powerbank | põhitoide
ESP32-S3-CAM | videopilt
VL53L0X | kauguse mõõtmine
QA011 ESP32 CAM | tulevane QR positsioneerimine

Siia vaja lisada

ühendusskeem
pinged erinevates sõlmedes energiatarbimise hinnang

# 4. Ajamiprototüüp

## Eesmärk

Kontrollida, et mootorid suudavad robotit liigutada.

## Teostus

Kasutatakse kahte N20 reduktormootorit.

Mootoreid juhitakse TB6612 draiveri kaudu.

Robot kasutab diferentsiaaljuhtimist:

edasi – mõlemad mootorid edasi tagasi – mõlemad mootorid tagasi

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
vasakule – mootorid vastassuundades paremale – mootorid vastassuundades

## Tulemus

Robot liigub:

edasi
tagasi
vasakule
paremale

Kohapeal pööramine töötab.

# 5. Sideprototüüp

## Eesmärk

Kontrollida juhtkäskude edastamist kasutajaseadmest robotile.

## Teostus

ESP32 töötab WiFi Access Point režiimis.

Robot loob oma võrgu.

Kasutaja ühendub:

telefoniga
sülearvutiga

juhtmevabalt roboti võrku.

Juhtkäsud saadetakse HTTP päringutena.

## Tulemus

Käsk jõuab ESP32-ni ning põhjustab vastava mootori liikumise.

# 6. Veebiliidese prototüüp

## Eesmärk

Kontrollida kasutajaliidest.

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
## Teostus

ESP32 teenindab veebilehte.

Veebiliides sisaldab juhtnuppe:

edasi
tagasi
vasakule
paremale
stop

## Tulemus

Nupu vajutamisel liigub robot vastavas suunas.

Veebiliides töötab:

Android telefonis
Windows sülearvutis
Siia vaja lisada

ekraanipildid veebiliidesest

# 7. Videopildi prototüüp

## Eesmärk

Kontrollida reaalajas videopildi edastamist.

## Teostus

ESP32-S3-CAM edastab videopildi WiFi kaudu.

Operaator saab videovoogu vaadata veebibrauseris.

## Tulemus

Video töötab samaaegselt juhtimisega.

Siia vaja lisada

videovoogude FPS mõõtmine
ekraanipildid

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
# 8. Andurite prototüüp

## VL53L0X kaugusandur

Eesmärk

Mõõta vastase kaugust.

Staatus

Andur olemas.

Siia vaja lisada

ühendusdiagramm
mõõtmistulemused
kauguse täpsuse analüüs

## Värviandur

Eesmärk

Tuvastada areeni piir.

Staatus

Siia vaja lisada:

kasutatav andur
ühendusskeem
testitulemused

# 9. Testimisplaan

## TEST-001 Mootorite töö

Eesmärk: kontrollida kõigi liikumissuundade toimimist.

Test:

edasi
tagasi
vasakule
paremale
stop

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
Läbitud kui:

robot täidab kõik käsud korrektselt.

## TEST-002 WiFi ühendus

Eesmärk: kontrollida võrgu stabiilsust.

Test:

ühendada robotiga vähemalt 10 korda järjest.

Läbitud kui:

ühendus luuakse edukalt igal katsel.

## TEST-003 Veebiliides

Eesmärk: kontrollida kasutajaliidest.

Test:

vajutada kõiki juhtnuppe.

Läbitud kui:

robot reageerib õigesti.

## TEST-004 Videopilt

Eesmärk: kontrollida videovoogu.

Test:

jälgida pilti vähemalt 5 minutit.

Läbitud kui:

videovoog ei katke.

## TEST-005 Kaugusandur

Eesmärk: kontrollida mõõtetäpsust.

Testkaugused:

10 cm
20 cm
50 cm
100 cm

Mõõta igal kaugusel 30 korda.

Läbitud kui:

keskmine viga jääb alla 5 cm.

## TEST-006 Värviandur

Eesmärk: eristada areeni ja piiri.

Testmaterjalid:

valge paber
must paber
punane pind

Läbitud kui:

värvid eristatakse korrektselt.

## TEST-007 Side latentsus

Eesmärk: mõõta juhtimise viivitust.

Metoodika:

100 käsku järjest.

Mõõdetakse:

keskmine latentsus
maksimaalne latentsus

Siia vaja lisada tulemused.

## TEST-008 Tõuketest

Eesmärk: hinnata roboti tõukejõudu.

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
Metoodika:

robot veab nööriga ühendatud raskust.

Mõõdetakse:

maksimaalne veetav mass.

Siia vaja lisada mõõtmistulemused.

# 10. Riskid

Risk | Mõju | Lahendus
Roomik puruneb | kõrge | varulülid
WiFi katkeb | keskmine | automaatne reconnect
Mootor kuumeneb | keskmine | PWM piirang
Aku tühjeneb | kõrge | aku seire
Kaamera hangub | keskmine | watchdog restart

# 11. Verstapost 3 plaan

Järgmisena lisatakse:

VL53L0X integreerimine
värviandur
QR koodide lugemine
positsioneerimine
autonoomne vastase otsing
PCB projekteerimine
Siia vaja lisada

KiCad skeem
PCB paigutus
BOM uuendus
CAD uuendus

# Kokkuvõte

Verstapost 2 eesmärgid on suuremas osas täidetud.

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
Valideeritud on:

✓ roomikšassii

✓ mootorijuhtimine

✓ WiFi side

✓ veebiliides

✓ videopilt

Järgmise verstaposti peamine eesmärk on andurite integreerimine ja autonoomsete funktsioonide arendamine.

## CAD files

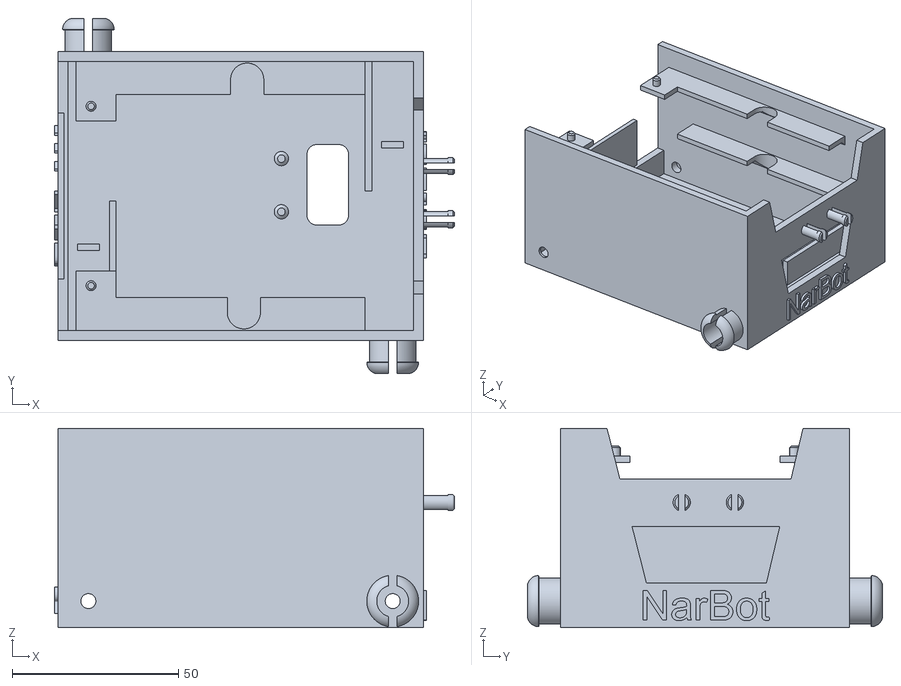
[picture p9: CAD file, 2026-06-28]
CAD/stl/stl_kere2.stl
120.4 x 107.0 x 60.0

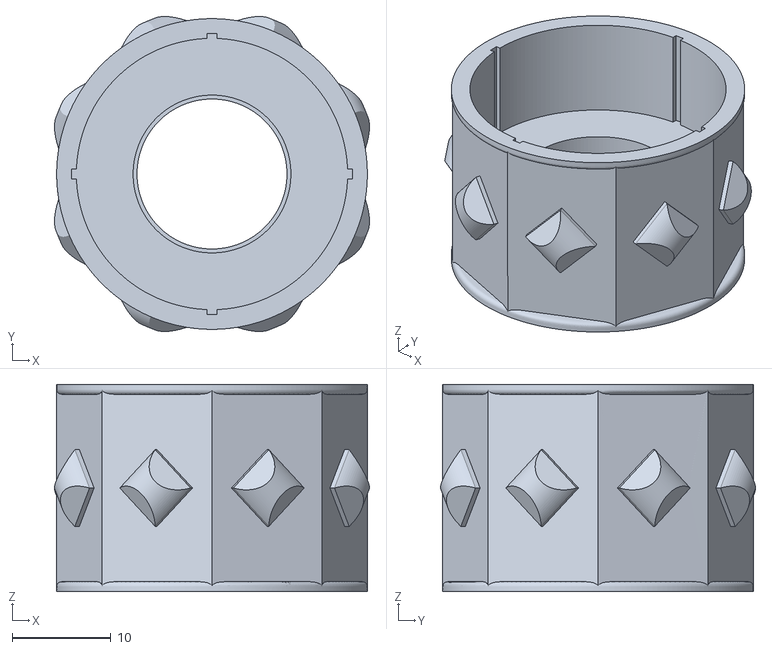
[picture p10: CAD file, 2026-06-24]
CAD/stl/stl_ratas_valimine_suur.stl
31.9 x 31.9 x 21.0

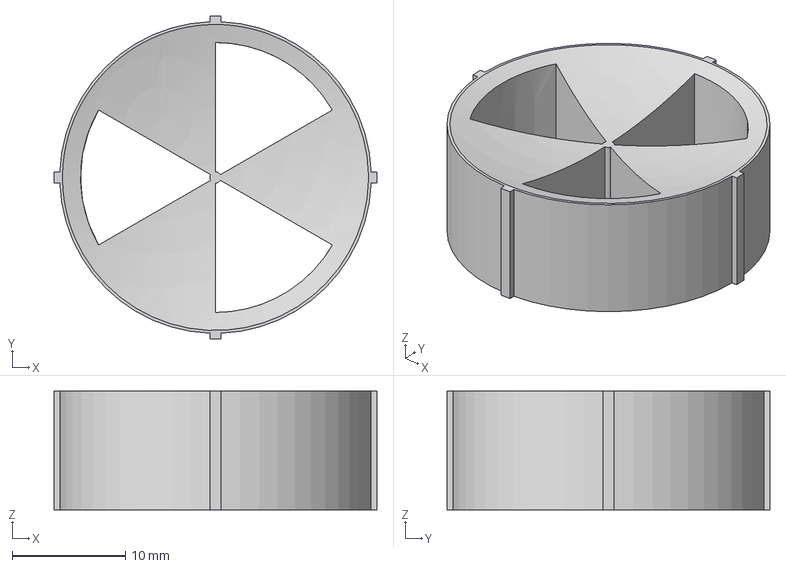
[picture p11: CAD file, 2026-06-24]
CAD/stl/stl_ratas_sisemine.step
28.5 x 28.5 x 10.5 mm

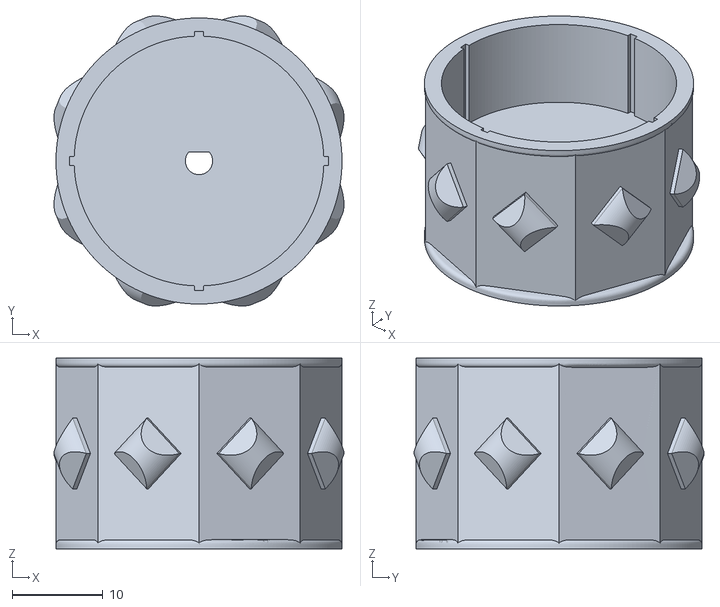
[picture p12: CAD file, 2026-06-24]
CAD/stl/stl_ratas_valimine_vaike.stl
31.9 x 31.9 x 21.0

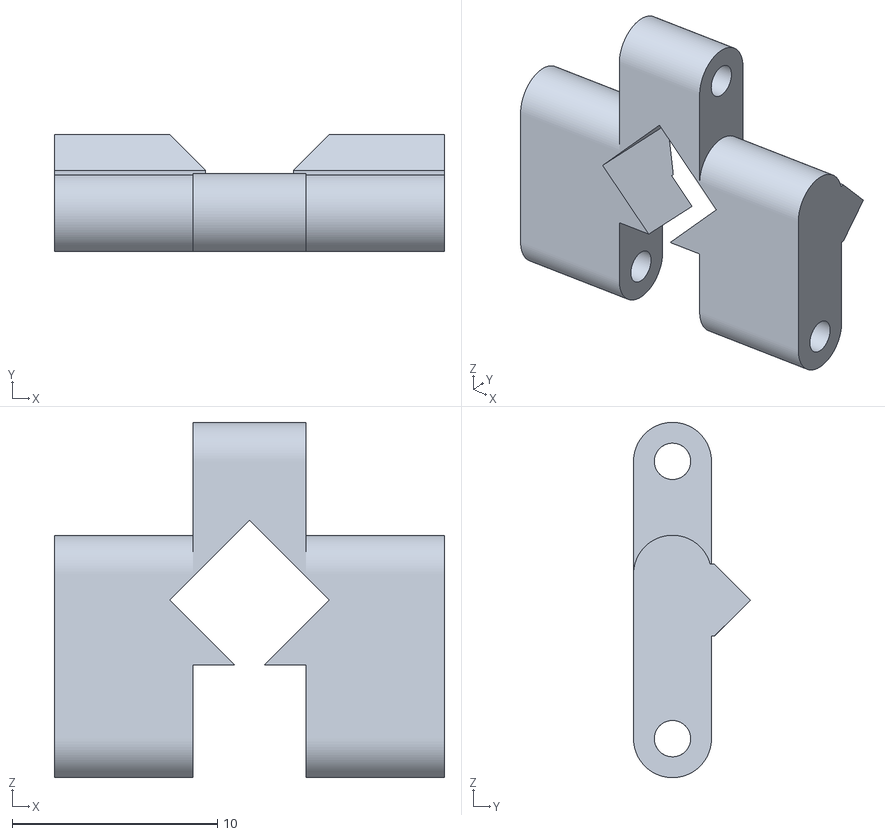
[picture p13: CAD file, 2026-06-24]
CAD/stl/stl_lyli.stl
19.0 x 5.70 x 17.3

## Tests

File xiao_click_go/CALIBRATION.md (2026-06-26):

# Click-And-Go Calibration Guide

This guide explains how to calibrate the XIAO click-and-go system once the robot is physically available.

The goal is to make this chain work:

```text
camera click in browser -> pixel coordinates -> ground coordinates -> HTTP command -> QR Reader XIAO -> motor driver
```

There are two separate calibrations:

1. Motion calibration: how long the robot must turn or drive.
2. Camera calibration: how a clicked pixel maps to a point on the floor.

You can prepare the printed calibration pattern and data tables before the robot is ready, but the actual numbers must be measured with the assembled robot.

## Files To Update After Calibration

Motion constants live in:

```text
qr_reader_xiao/src/main.cpp
```

Update:

```cpp
static constexpr float TURN_MS_PER_DEG = 8.0f;
static constexpr float DRIVE_MS_PER_CM = 35.0f;
```

Camera calibration lives in the browser script embedded in the same file:

```js
const CALIBRATION = {
  enabled: false,
  H: [
    [1, 0, 0],
    [0, 1, 0],
    [0, 0, 1],
  ],
};
```

After camera calibration, set `enabled` to `true` and replace `H` with the measured homography matrix.

## Required Equipment

- Assembled robot with fixed XIAO ESP32-S3 Sense camera position
- FrontCam XIAO with color sensor
- QR Reader XIAO with motor driver and distance sensor
- Laptop or phone connected to the FrontCam `SumoVision` Wi-Fi access point
- Ruler or measuring tape
- Printed checkerboard calibration sheet
- Masking tape or marker for fixed start position
- Flat test floor with enough space for 1 m forward driving

## Link Setup Check

Before measuring anything:

1. Flash the XIAO click-and-go firmware.
2. Flash the QR Reader XIAO firmware.
3. Start FrontCam first, then reset QR Reader so it joins `SumoVision` as `192.168.4.2`.

4. Open the XIAO UI:

```text
http://192.168.4.1
```

5. Check the live stream:

```text
http://192.168.4.1:81/stream
```

6. Check a still frame:

```text
http://192.168.4.1/capture
```

7. Check QR Reader status:

```text
http://192.168.4.2/api/status
```

8. Press `STOP` in the UI and confirm the QR Reader responds:

```json
{"status":"stopped","motor":{"last_command":"s","left_speed":0,"right_speed":0}}
```

Do not continue calibration until the browser can reliably call `http://192.168.4.2/api/status` and `POST http://192.168.4.2/api/stop`.

## Part 1: Motion Calibration

The first version of click-and-go uses open-loop motion. The QR Reader XIAO applies timed motor states:

```text
turn left/right for N milliseconds
stop briefly
drive forward for M milliseconds
stop
```

Because there are no wheel encoders yet, the timing constants must be measured on the real robot.

### 1.1 Measure Turn Rate

1. Put the robot on the floor.
2. Mark the robot's starting direction with tape.
3. Send a right-turn command for a known time, for example `1000 ms`.
4. Measure the angle turned in degrees.
5. Repeat at least 5 times.
6. Do the same for left turns.

Use this formula:

```text
TURN_MS_PER_DEG = turn_time_ms / measured_angle_deg
```

Example:

```text
1000 ms / 125 deg = 8.0 ms/deg
```

Record results:

| Trial | Direction | Time (ms) | Angle (deg) | ms/deg |
| --- | --- | ---: | ---: | ---: |
| 1 | Right | 1000 |  |  |
| 2 | Right | 1000 |  |  |
| 3 | Right | 1000 |  |  |
| 4 | Left | 1000 |  |  |
| 5 | Left | 1000 |  |  |

Use the median `ms/deg` value, not the best-looking single trial.

If left and right are very different, document both values. For the current firmware, use the average as the first approximation.

### 1.2 Measure Forward Drive Rate

1. Mark a start line on the floor.
2. Put the robot's reference point on the start line.
3. Send a forward command for a known time, for example `1000 ms`.
4. Measure the distance travelled in centimeters.
5. Repeat at least 5 times.

Use this formula:

```text
DRIVE_MS_PER_CM = drive_time_ms / measured_distance_cm
```

Example:

```text
1000 ms / 28 cm = 35.7 ms/cm
```

Record results:

| Trial | Time (ms) | Distance (cm) | ms/cm |
| --- | ---: | ---: | ---: |
| 1 | 1000 |  |  |
| 2 | 1000 |  |  |
| 3 | 1000 |  |  |
| 4 | 1000 |  |  |
| 5 | 1000 |  |  |

Use the median `ms/cm` value.

### 1.3 Update Firmware Constants

Open:

```text
qr_reader_xiao/src/main.cpp
```

Update:

```cpp
static constexpr float TURN_MS_PER_DEG = 8.0f;
static constexpr float DRIVE_MS_PER_CM = 35.0f;
```

Rebuild and upload:

```powershell
$env:PYTHONUTF8='1'
$env:PYTHONIOENCODING='utf-8'
..\venv\Scripts\pio.exe run --target upload
```

## Part 2: Camera Calibration

Camera calibration maps a click on the camera image to a floor coordinate relative to the robot.

Coordinate convention:

```text
X = forward from robot center, in cm
Y = right from robot center, in cm
Angle 0 deg = straight ahead
Positive angle = turn right
Negative angle = turn left
```

### 2.1 Print Checkerboard

Recommended pattern:

```text
8 x 10 squares
25 mm square size
7 x 9 internal corners
A4 paper
Printed at 100% scale
```

Important:

- Print at actual size.
- Do not use "fit to page".
- Measure one printed square with a ruler.
- Write down the real square size.

Record:

```text
Printed square size: ____ mm
```

### 2.2 Place Robot And Checkerboard

1. Put the robot on the floor.
2. Mark the robot start position and direction with tape.
3. Place the checkerboard flat on the floor in front of the robot.
4. Make sure the full checkerboard is visible in the camera image.
5. Measure the distance from the robot rotation center to the checkerboard center.

Record:

```text
Checkerboard center X0: ____ cm forward
Checkerboard center Y0: ____ cm right
```

If the checkerboard is centered on the robot's forward axis, `Y0 = 0`.

### 2.3 Capture Calibration Image

Open:

```text
http://192.168.4.1/capture
```

Save the image as:

```text
calibration_frame.jpg
```

The image is valid only if:

- all internal checkerboard corners are visible;
- the image is not motion-blurred;
- the checkerboard is flat on the ground;
- lighting is close to the real operating environment.

### 2.4 Compute Homography

The homography matrix `H` should be computed from:

- detected checkerboard pixel corners;
- known real-world checkerboard corner positions in centimeters.

The output format must be:

```js
H: [
  [h00, h01, h02],
  [h10, h11, h12],
  [h20, h21, h22],
]
```

The current browser code applies it like this:

```js
ground_x_cm = (h00 * px + h01 * py + h02) / (h20 * px + h21 * py + h22)
ground_y_cm = (h10 * px + h11 * py + h12) / (h20 * px + h21 * py + h22)
```

If using OpenCV, the expected function is:

```python
cv2.findHomography(pixel_points, floor_points, cv2.RANSAC)
```

### 2.5 Update Browser Calibration Matrix

Open:

```text
xiao_click_go/src/main.cpp
```

Find:

```js
const CALIBRATION = {
  enabled: false,
  H: [
    [1, 0, 0],
    [0, 1, 0],
    [0, 0, 1],
  ],
};
```

Change it to:

```js
const CALIBRATION = {
  enabled: true,
  H: [
    [/* measured h00 */, /* measured h01 */, /* measured h02 */],
    [/* measured h10 */, /* measured h11 */, /* measured h12 */],
    [/* measured h20 */, /* measured h21 */, /* measured h22 */],
  ],
};
```

Rebuild and upload the firmware.

## Part 3: Validation

After both calibrations are entered, test the complete click-and-go behavior.

### 3.1 Static Coordinate Test

1. Put a small object at a known floor position.
2. Example: `60 cm forward, 20 cm right`.
3. Click that object in the browser camera image.
4. Check the displayed ground coordinate.

Record:

| Target X (cm) | Target Y (cm) | Measured X (cm) | Measured Y (cm) | Error (cm) |
| ---: | ---: | ---: | ---: | ---: |
| 60 | 20 |  |  |  |
| 40 | -20 |  |  |  |
| 80 | 0 |  |  |  |

Acceptable first target:

```text
Median coordinate error <= 5 cm
```

If error is larger near image edges, avoid edge clicks or redo calibration with the checkerboard covering more of the useful camera area.

### 3.2 Driving Test

1. Put the robot at the marked start position.
2. Click a point about `40 cm` straight ahead.
3. Confirm the robot drives roughly to that point.
4. Click a point diagonally right.
5. Confirm the robot turns right first, then drives.
6. Click a point diagonally left.
7. Confirm the robot turns left first, then drives.

Record:

| Trial | Target Description | Result | Notes |
| --- | --- | --- | --- |
| 1 | 40 cm straight ahead |  |  |
| 2 | diagonal right |  |  |
| 3 | diagonal left |  |  |

### 3.3 Safety Check

Always verify:

- STOP button stops the robot immediately.
- Clicks do not create excessive movement duration.
- Robot does not drive outside the test area.
- QR Reader XIAO rejects invalid commands and stops on `cmd=s`.

## Troubleshooting

| Problem | Likely Cause | Fix |
| --- | --- | --- |
| Camera stream is blank | Camera init or power issue | Check serial monitor and camera ribbon cable |
| Clicks do nothing | QR Reader HTTP API is offline or blocked | Check `http://192.168.4.2/api/status` from the same browser |
| Robot turns the wrong way | Motor mapping inverted | Swap left/right command mapping or motor wiring |
| Robot drives too far | `DRIVE_MS_PER_CM` too high | Re-measure forward distance |
| Robot stops short | `DRIVE_MS_PER_CM` too low | Re-measure forward distance |
| Robot over-rotates | `TURN_MS_PER_DEG` too high | Re-measure turn angle |
| Robot under-rotates | `TURN_MS_PER_DEG` too low | Re-measure turn angle |
| Coordinates are wrong everywhere | Bad homography | Redo checkerboard capture and measurements |
| Coordinates are good in center but bad at edges | Lens distortion or weak calibration coverage | Click closer to image center or use a wider calibration area |

## Calibration Data Summary

Fill this section after testing:

```text
Robot:
Camera mount:
Motor driver:
QR Reader IP:
Speed used:

TURN_MS_PER_DEG:
DRIVE_MS_PER_CM:

Checkerboard square size:
Checkerboard X0:
Checkerboard Y0:

Homography H:
[
  [__, __, __],
  [__, __, __],
  [__, __, __],
]

Median static coordinate error:
Median driving endpoint error:
Known limitations:
```

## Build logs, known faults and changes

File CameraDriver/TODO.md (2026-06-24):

# SMARS Robot Motor Control — Code Specification

## Goal

Create firmware for **ESP32-CAM** that controls **two DC motors** through an **L298N** motor driver for bench testing.

This is the **first stage only**:
- no camera logic yet
- no red-dot detection yet
- no chassis logic yet

The code must only prove that the robot can drive its motors correctly.

---

## Hardware

- **Board:** ESP32-CAM
- **Motor driver:** L298N
- **Motors:** 2 × G12-N20 geared DC motors

---

## Wiring Assumptions

### ESP32-CAM to L298N
- `GPIO13` → `IN1`
- `GPIO14` → `IN2`
- `GPIO15` → `IN3`
- `GPIO12` → `IN4`
- `GND` → `GND`

### L298N
- `OUT1`, `OUT2` → left motor
- `OUT3`, `OUT4` → right motor
- `ENA`, `ENB` jumpers remain installed for now

### Power
- L298N motor power comes from external supply
- ESP32-CAM is powered separately
- grounds must be shared

---

## Functional Requirements

The firmware must:

1. initialize all motor control pins as outputs
2. stop both motors on startup
3. open serial communication at `115200`
4. accept single-character commands from serial input
5. control motor direction based on commands

---

## Required Commands

### Movement commands
- `f` → drive forward
- `b` → drive backward
- `l` → turn left
- `r` → turn right
- `s` → stop

### Behavior
- each command must immediately change motor state
- unknown characters may be ignored

---

## Motor Logic

### Left motor
Controlled by:
- `IN1`
- `IN2`

### Right motor
Controlled by:
- `IN3`
- `IN4`

### Direction rules
For each motor:
- forward = first pin `HIGH`, second pin `LOW`
- backward = first pin `LOW`, second pin `HIGH`
- stop = both pins `LOW`

---

## Startup Behavior

On boot, the firmware must:
1. start serial output
2. configure pins
3. stop motors
4. print a short help message showing available commands

---

## Serial Output

The code should print:
- a startup banner
- available commands
- a short message whenever a valid command is received

Example:
- `Forward`
- `Backward`
- `Left`
- `Right`
- `Stop`

---

## Non-Goals for This Version

This version does **not** need:
- PWM speed control
- camera initialization
- Wi-Fi
- web server
- autonomous driving
- red color detection
- obstacle detection
- dual camera support

---

## Acceptance Criteria

The code is considered complete when:

1. the ESP32-CAM boots successfully
2. serial monitor works at `115200`
3. entering `f` spins both motors forward
4. entering `b` spins both motors backward
5. entering `l` turns left
6. entering `r` turns right
7. entering `s` stops both motors

---

## Next Version

After this version works, the next stage should add:
1. safer flashing workflow notes for ESP32-CAM
2. optional PWM speed control
3. integration with front camera logic
4. conversion from manual commands to autonomous steering

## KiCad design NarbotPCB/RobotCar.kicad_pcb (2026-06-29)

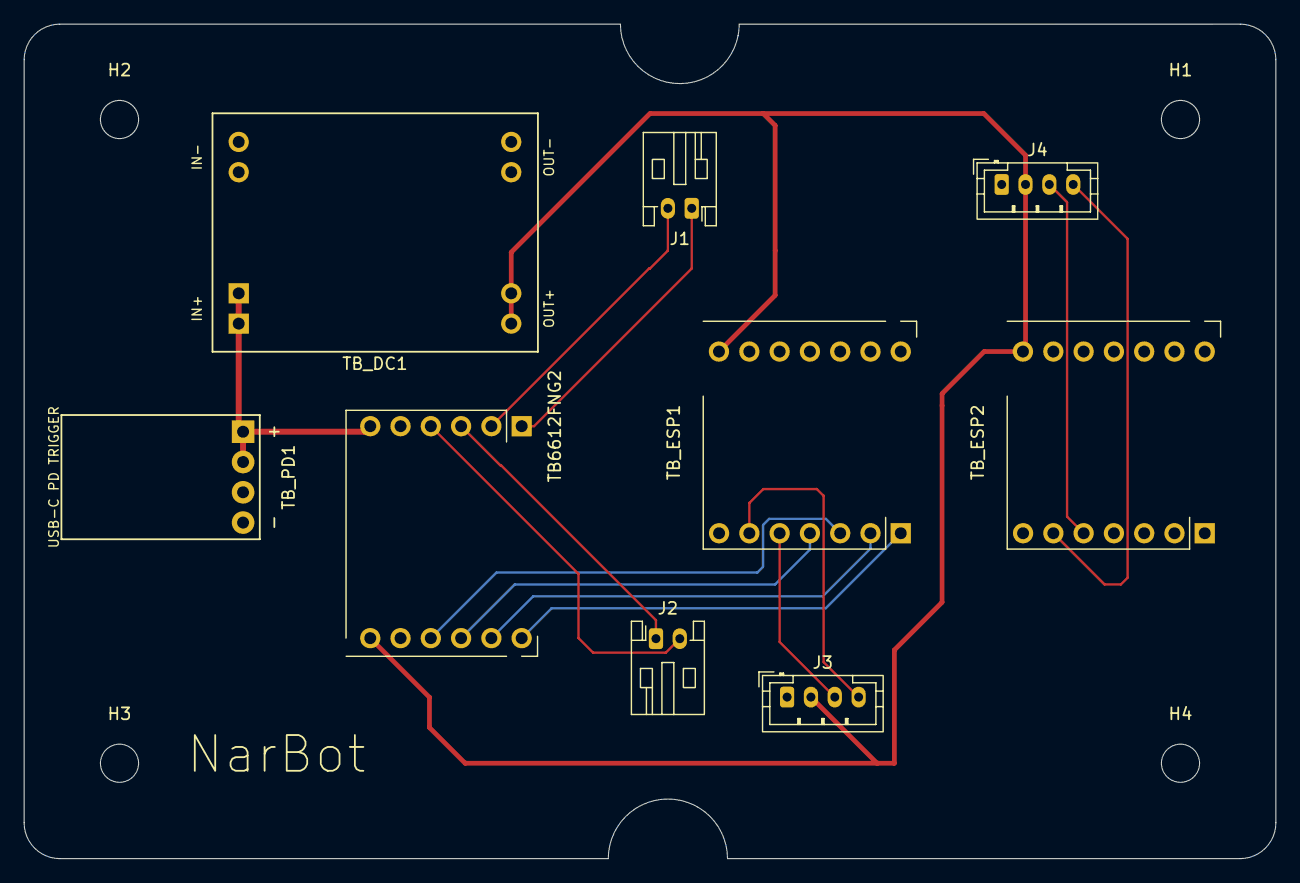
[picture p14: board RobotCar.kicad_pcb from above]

Board: 2 copper layers, 105.0 x 70.0 mm, 13 parts (0 on the bottom side), 15 nets.

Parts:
H1, H2, H3, H4: MountingHole; MountingHole_3.2mm_M3
J1: Motor_1_Conn; JST_PH_S2B-PH-K_1x02_P2.00mm_Horizontal
J2: Motor_2_Conn; JST_PH_S2B-PH-K_1x02_P2.00mm_Horizontal
J3: ColorI2C; JST_PH_B4B-PH-K_1x04_P2.00mm_Vertical
J4: DistanceI2C; JST_PH_B4B-PH-K_1x04_P2.00mm_Vertical
TB6612FNG2: Motor_DF_Robot_Through_Hole
TB_DC1: DFRobot_DFR1015_Socket_Carrier_2.54mm
TB_ESP1, TB_ESP2: Seeed_XIAO_Sense_2x07_SMD_Socket_12.70mm
TB_PD1: OKY3404_PDC004_PD_Trigger_Socket_1x04

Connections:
+5V: J3.2, J4.2, TB6612FNG2.12 (VCC), TB_DC1.3 (OUT+), TB_ESP1.14 (5V), TB_ESP2.14 (5V)
+12V: TB6612FNG2.6 (VM), TB_DC1.1 (IN+), TB_PD1.1 (OUT+)
/DIR1: TB6612FNG2.7 (DIR1), TB_ESP1.1 (D0)
/DIR2: TB6612FNG2.10 (DIR2), TB_ESP1.3 (D2)
/PWM1: TB6612FNG2.8 (PWM1), TB_ESP1.2 (D1)
/PWM2: TB6612FNG2.9 (PWM2), TB_ESP1.4 (D3)
/SCL_1: J3.4, TB_ESP1.6 (SCL/D5)
/SCL_2: J4.4, TB_ESP2.6 (SCL/D5)
/SDA_1: J3.3, TB_ESP1.5 (SDA/D4)
/SDA_2: J4.3, TB_ESP2.5 (SDA/D4)
GND: J3.1, J4.1, TB6612FNG2.5 (GND), TB6612FNG2.11 (GND), TB_DC1.2 (IN-), TB_DC1.4 (OUT-), TB_ESP1.13 (GND), TB_ESP2.13 (GND), TB_PD1.2 (OUT-)
unnamed: J1.1, TB6612FNG2.1 (M1+)
unnamed: J1.2, TB6612FNG2.2 (M1-)
unnamed: J2.1, TB6612FNG2.3 (M2+)
unnamed: J2.2, TB6612FNG2.4 (M2-)

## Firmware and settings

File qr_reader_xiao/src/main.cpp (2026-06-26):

#include <Arduino.h>
#include <WebServer.h>
#include <WiFi.h>
#include <Wire.h>
#include "esp_camera.h"
#include "esp_http_server.h"

#if !defined(CAMERA_MODEL_XIAO_ESP32S3)
#error "CAMERA_MODEL_XIAO_ESP32S3 must be defined in platformio.ini"
#endif

// XIAO ESP32-S3 Sense camera pins.
// Source: Seeed Studio XIAO ESP32S3 Sense camera example.
#define PWDN_GPIO_NUM -1
#define RESET_GPIO_NUM -1
#define XCLK_GPIO_NUM 10
#define SIOD_GPIO_NUM 40
#define SIOC_GPIO_NUM 39
#define Y9_GPIO_NUM 48
#define Y8_GPIO_NUM 11
#define Y7_GPIO_NUM 12
#define Y6_GPIO_NUM 14
#define Y5_GPIO_NUM 16
#define Y4_GPIO_NUM 18
#define Y3_GPIO_NUM 17
#define Y2_GPIO_NUM 15
#define VSYNC_GPIO_NUM 38
#define HREF_GPIO_NUM 47
#define PCLK_GPIO_NUM 13

static const char *WIFI_SSID = "SumoVision";
static const char *WIFI_PASSWORD = "sumo1234";
static const IPAddress LOCAL_IP(192, 168, 4, 2);
static const IPAddress GATEWAY(192, 168, 4, 1);
static const IPAddress SUBNET(255, 255, 255, 0);
static const IPAddress DNS_SERVER(192, 168, 4, 1);

// DFRobot dual motor driver pins on the QR reader board.
// Adjust these constants if the breadboard wiring changes.
static constexpr uint8_t MOTOR_DIR1_PIN = D0;
static constexpr uint8_t MOTOR_PWM1_PIN = D1;
static constexpr uint8_t MOTOR_PWM2_PIN = D2;
static constexpr uint8_t MOTOR_DIR2_PIN = D3;
static constexpr bool MOTOR1_FORWARD_HIGH = true;
static constexpr bool MOTOR2_FORWARD_HIGH = true;
static constexpr bool MOTOR_OUTPUTS_ENABLED = true;
// Leave LEDC channel 0 to the camera XCLK generator.
static constexpr uint8_t MOTOR1_PWM_CHANNEL = 4;
static constexpr uint8_t MOTOR2_PWM_CHANNEL = 5;
static constexpr uint32_t MOTOR_PWM_FREQUENCY = 20000;
static constexpr uint8_t MOTOR_PWM_RESOLUTION = 8;

// M5Stack Unit Sonic-style distance sensor on the QR reader board.
static constexpr uint8_t DISTANCE_SDA_PIN = D4;
static constexpr uint8_t DISTANCE_SCL_PIN = D5;
static constexpr uint8_t DISTANCE_I2C_ADDRESS = 0x57;
static constexpr unsigned long DISTANCE_READ_INTERVAL_MS = 350;
static constexpr unsigned long DISTANCE_MEASUREMENT_MS = 120;
static constexpr uint16_t DISTANCE_MAX_VALID_MM = 4500;
static constexpr bool DISTANCE_AUTO_STOP_ENABLED = false;
static constexpr uint16_t DISTANCE_AUTO_STOP_MM = 120;

static constexpr uint16_t HTTP_PORT = 80;
static constexpr uint16_t STREAM_PORT = 81;
static constexpr unsigned long WIFI_RECONNECT_INTERVAL_MS = 5000;

// Open-loop tuning constants. Replace with measured values after robot calibration.
static constexpr float TURN_MS_PER_DEG = 8.0f;
static constexpr float DRIVE_MS_PER_CM = 35.0f;
static constexpr uint16_t DEFAULT_SPEED = 150;
static constexpr uint16_t TURN_SETTLE_MS = 150;
static constexpr uint16_t MAX_TURN_MS = 1600;
static constexpr uint16_t MAX_DRIVE_MS = 3000;

static WebServer web(HTTP_PORT);
static httpd_handle_t streamHttpd = nullptr;

enum class MotionPhase {
  IDLE,
  TURNING,
  TURN_SETTLE,
  DRIVING,
  MANUAL,
  DONE
};

struct MotionPlan {
  MotionPhase phase = MotionPhase::IDLE;
  int turnDir = 0;
  uint16_t turnMs = 0;
  uint16_t driveMs = 0;
  uint16_t speed = DEFAULT_SPEED;
  unsigned long deadlineMs = 0;
  String lastError;
};

struct DistanceReading {
  bool online = false;
  float mm = 0.0f;
  bool inRange = false;
  String error;
  unsigned long readCount = 0;
  unsigned long lastReadMs = 0;
};

static MotionPlan plan;
static DistanceReading distanceReading;
static unsigned long requestCount = 0;
static unsigned long commandCount = 0;
static unsigned long lastReconnectAttemptMs = 0;
static String lastMotorCommand = "s";
static int lastLeftSpeed = 0;
static int lastRightSpeed = 0;
static String lastQrId = "";
static unsigned long qrCount = 0;
static bool distanceReadPending = false;
static unsigned long distanceRequestMs = 0;

static const char INDEX_HTML[] PROGMEM = R"rawliteral(
<!doctype html>
<html lang="en">
<head>
  <meta charset="utf-8">
  <meta name="viewport" content="width=device-width, initial-scale=1">
  <title>QR Reader Robot Node</title>
  <style>
    :root {
      color-scheme: dark;
      --bg: #101114;
      --panel: #1a1d22;
      --text: #f2f5f8;
      --muted: #98a2b3;
      --line: #343b46;
      --accent: #31c48d;
      --danger: #f05252;
    }
    * { box-sizing: border-box; }
    body {
      margin: 0;
      background: var(--bg);
      color: var(--text);
      font-family: system-ui, -apple-system, BlinkMacSystemFont, "Segoe UI", sans-serif;
    }
    main {
      width: min(900px, 100%);
      margin: 0 auto;
      padding: 16px;
      display: grid;
      gap: 12px;
    }
    section {
      background: var(--panel);
      border: 1px solid var(--line);
      border-radius: 8px;
      padding: 12px;
    }
    h1, h2, p { margin: 0; }
    h1 { font-size: 20px; }
    h2 { font-size: 15px; margin-bottom: 8px; }
    .muted { color: var(--muted); font-size: 13px; margin-top: 4px; }
    img {
      display: block;
      width: 100%;
      min-height: 240px;
      object-fit: contain;
      border: 1px solid var(--line);
      border-radius: 8px;
      background: #050608;
    }
    .row {
      display: grid;
      grid-template-columns: repeat(5, 1fr);
      gap: 8px;
    }
    button {
      border: 0;
      border-radius: 8px;
      min-height: 40px;
      padding: 0 10px;
      font-weight: 700;
      color: #06100c;
      background: var(--accent);
      cursor: pointer;
    }
    button.stop { background: var(--danger); color: #fff; }
    pre {
      white-space: pre-wrap;
      overflow-wrap: anywhere;
      background: #0b0d10;
      border: 1px solid var(--line);
      border-radius: 8px;
      padding: 9px;
      color: var(--muted);
      min-height: 72px;
      margin: 0;
      font-size: 12px;
    }
    a { color: var(--accent); }
    @media (max-width: 620px) {
      .row { grid-template-columns: 1fr; }
    }
  </style>
</head>
<body>
<main>
  <section>
    <h1>QR Reader Robot Node</h1>
    <p class="muted">This board serves the QR camera, reads the distance sensor, and drives the motor driver.</p>
  </section>
  <section>
    <h2>QR camera</h2>
    <img id="stream" alt="QR reader camera stream">
    <p class="muted">Stream: <a href="http://192.168.4.2:81/stream">http://192.168.4.2:81/stream</a></p>
  </section>
  <section>
    <h2>Manual motor test</h2>
    <div class="row">
      <button data-cmd="l">Left</button>
      <button data-cmd="f">Forward</button>
      <button class="stop" data-cmd="s">Stop</button>
      <button data-cmd="b">Back</button>
      <button data-cmd="r">Right</button>
    </div>
  </section>
  <section>
    <h2>Status</h2>
    <pre id="status">Loading...</pre>
  </section>
</main>
<script>
const statusBox = document.getElementById("status");
document.getElementById("stream").src = `http://${location.hostname}:81/stream`;

async function fetchJson(url, options = {}) {
  const response = await fetch(url, options);
  if (!response.ok) throw new Error(`${url} returned ${response.status}`);
  return response.json();
}

async function refreshStatus() {
  const data = await fetchJson("/api/status");
  statusBox.textContent = JSON.stringify(data, null, 2);
}

async function command(cmd) {
  const data = await fetchJson(`/api/command?cmd=${cmd}&speed=130`, { method: "POST" });
  statusBox.textContent = JSON.stringify(data, null, 2);
}

document.querySelectorAll("[data-cmd]").forEach((button) => {
  button.addEventListener("click", () => void command(button.dataset.cmd));
});

void refreshStatus();
window.setInterval(() => void refreshStatus(), 1500);
</script>
</body>
</html>
)rawliteral";

const char *phaseName(MotionPhase phase) {
  switch (phase) {
    case MotionPhase::IDLE:
      return "idle";
    case MotionPhase::TURNING:
      return "turning";
    case MotionPhase::TURN_SETTLE:
      return "turn_settle";
    case MotionPhase::DRIVING:
      return "driving";
    case MotionPhase::MANUAL:
      return "manual";
    case MotionPhase::DONE:
      return "done";
  }
  return "unknown";
}

String jsonEscape(const String &value) {
  String escaped;
  escaped.reserve(value.length() + 8);
  for (size_t i = 0; i < value.length(); i++) {
    const char c = value[i];
    if (c == '"' || c == '\\') {
      escaped += '\\';
    } else if (c == '\n') {
      escaped += "\\n";
      continue;
    } else if (c == '\r') {
      continue;
    }
    escaped += c;
  }
  return escaped;
}

uint16_t boundedDuration(long value, uint16_t maxValue) {
  if (value < 0) {
    return 0;
  }
  if (value > maxValue) {
    return maxValue;
  }
  return static_cast<uint16_t>(value);
}

uint16_t boundedSpeed(long value) {
  if (value < 0) {
    return 0;
  }
  if (value > 255) {
    return 255;
  }
  return static_cast<uint16_t>(value);
}

void addCorsHeaders() {
  web.sendHeader("Access-Control-Allow-Origin", "*");
  web.sendHeader("Access-Control-Allow-Methods", "GET, POST, OPTIONS");
  web.sendHeader("Access-Control-Allow-Headers", "Content-Type");
  web.sendHeader("Cache-Control", "no-store");
}

void writeMotor(uint8_t dirPin, uint8_t pwmChannel, int speed, bool forwardHigh) {
  const int clamped = constrain(speed, -255, 255);
  const bool forward = clamped >= 0;
  const uint8_t pwm = static_cast<uint8_t>(abs(clamped));
  digitalWrite(dirPin, forward == forwardHigh ? HIGH : LOW);
  ledcWrite(pwmChannel, MOTOR_OUTPUTS_ENABLED ? pwm : 0);
}

void setMotorSpeeds(int leftSpeed, int rightSpeed) {
  lastLeftSpeed = constrain(leftSpeed, -255, 255);
  lastRightSpeed = constrain(rightSpeed, -255, 255);
  writeMotor(MOTOR_DIR1_PIN, MOTOR1_PWM_CHANNEL, lastLeftSpeed, MOTOR1_FORWARD_HIGH);
  writeMotor(MOTOR_DIR2_PIN, MOTOR2_PWM_CHANNEL, lastRightSpeed, MOTOR2_FORWARD_HIGH);
}

void stopMotors() {
  lastMotorCommand = "s";
  setMotorSpeeds(0, 0);
}

void driveForward(uint16_t speed) {
  lastMotorCommand = "f";
  setMotorSpeeds(speed, speed);
}

void driveBackward(uint16_t speed) {
  lastMotorCommand = "b";
  setMotorSpeeds(-static_cast<int>(speed), -static_cast<int>(speed));
}

void turnLeft(uint16_t speed) {
  lastMotorCommand = "l";
  setMotorSpeeds(-static_cast<int>(speed), speed);
}

void turnRight(uint16_t speed) {
  lastMotorCommand = "r";
  setMotorSpeeds(speed, -static_cast<int>(speed));
}

void setupMotors() {
  pinMode(MOTOR_DIR1_PIN, OUTPUT);
  pinMode(MOTOR_DIR2_PIN, OUTPUT);
  ledcSetup(MOTOR1_PWM_CHANNEL, MOTOR_PWM_FREQUENCY, MOTOR_PWM_RESOLUTION);
  ledcSetup(MOTOR2_PWM_CHANNEL, MOTOR_PWM_FREQUENCY, MOTOR_PWM_RESOLUTION);
  ledcAttachPin(MOTOR_PWM1_PIN, MOTOR1_PWM_CHANNEL);
  ledcAttachPin(MOTOR_PWM2_PIN, MOTOR2_PWM_CHANNEL);
  stopMotors();
}

void finishDistanceRead() {
  const uint8_t received = Wire.requestFrom(DISTANCE_I2C_ADDRESS, static_cast<uint8_t>(3));
  if (received != 3) {
    distanceReading.online = false;
    distanceReading.error = "I2C read failed";
    distanceReadPending = false;
    return;
  }

  const uint32_t raw = (static_cast<uint32_t>(Wire.read()) << 16) |
                       (static_cast<uint32_t>(Wire.read()) << 8) |
                       static_cast<uint32_t>(Wire.read());
  const float distanceMm = static_cast<float>(raw) / 1000.0f;

  distanceReading.mm = distanceMm;
  distanceReading.inRange = distanceMm > 0.0f && distanceMm <= DISTANCE_MAX_VALID_MM;
  distanceReading.online = true;
  distanceReading.error = "";
  distanceReading.readCount++;
  distanceReadPending = false;

  if (DISTANCE_AUTO_STOP_ENABLED && plan.phase != MotionPhase::IDLE && plan.phase != MotionPhase::DONE &&
      distanceReading.inRange && distanceReading.mm < DISTANCE_AUTO_STOP_MM) {
    stopMotors();
    plan.phase = MotionPhase::DONE;
    plan.lastError = "distance auto-stop";
  }
}

bool updateDistanceSensor(bool force = false) {
  const unsigned long now = millis();

  if (distanceReadPending) {
    if (force || now - distanceRequestMs >= DISTANCE_MEASUREMENT_MS) {
      if (force && now - distanceRequestMs < DISTANCE_MEASUREMENT_MS) {
        delay(DISTANCE_MEASUREMENT_MS - (now - distanceRequestMs));
      }
      finishDistanceRead();
    }
    return distanceReading.online;
  }

  if (!force && now - distanceReading.lastReadMs < DISTANCE_READ_INTERVAL_MS) {
    return distanceReading.online;
  }

  Wire.beginTransmission(DISTANCE_I2C_ADDRESS);
  Wire.write(0x01);
  if (Wire.endTransmission() != 0) {
    distanceReading.online = false;
    distanceReading.error = "I2C write failed";
    return false;
  }

  distanceReading.lastReadMs = now;
  distanceRequestMs = now;
  distanceReadPending = true;

  if (force) {
    delay(DISTANCE_MEASUREMENT_MS);
    finishDistanceRead();
  }

  return distanceReading.online;
}

void cancelMotion() {
  plan.phase = MotionPhase::IDLE;
  plan.deadlineMs = 0;
  stopMotors();
}

void scheduleMotion(int turnDir, uint16_t turnMs, uint16_t driveMs, uint16_t speed) {
  cancelMotion();

  plan.turnDir = turnDir < 0 ? -1 : (turnDir > 0 ? 1 : 0);
  plan.turnMs = turnMs;
  plan.driveMs = driveMs;
  plan.speed = speed;
  plan.lastError = "";

  if (plan.turnDir != 0 && plan.turnMs > 0) {
    plan.turnDir > 0 ? turnRight(plan.speed) : turnLeft(plan.speed);
    plan.phase = MotionPhase::TURNING;
    plan.deadlineMs = millis() + plan.turnMs;
    return;
  }

  if (plan.driveMs > 0) {
    driveForward(plan.speed);
    plan.phase = MotionPhase::DRIVING;
    plan.deadlineMs = millis() + plan.driveMs;
    return;
  }

  plan.phase = MotionPhase::DONE;
}

void updateMotionPlan() {
  if (plan.phase == MotionPhase::IDLE || plan.phase == MotionPhase::DONE || plan.phase == MotionPhase::MANUAL) {
    return;
  }

  const long remaining = static_cast<long>(plan.deadlineMs - millis());
  if (remaining > 0) {
    return;
  }

  if (plan.phase == MotionPhase::TURNING) {
    stopMotors();
    plan.phase = MotionPhase::TURN_SETTLE;
    plan.deadlineMs = millis() + TURN_SETTLE_MS;
    return;
  }

  if (plan.phase == MotionPhase::TURN_SETTLE) {
    if (plan.driveMs > 0) {
      driveForward(plan.speed);
      plan.phase = MotionPhase::DRIVING;
      plan.deadlineMs = millis() + plan.driveMs;
    } else {
      plan.phase = MotionPhase::DONE;
    }
    return;
  }

  if (plan.phase == MotionPhase::DRIVING) {
    stopMotors();
    plan.phase = MotionPhase::DONE;
  }
}

bool initCamera() {
  camera_config_t config;
  config.ledc_channel = LEDC_CHANNEL_0;
  config.ledc_timer = LEDC_TIMER_0;
  config.pin_d0 = Y2_GPIO_NUM;
  config.pin_d1 = Y3_GPIO_NUM;
  config.pin_d2 = Y4_GPIO_NUM;
  config.pin_d3 = Y5_GPIO_NUM;
  config.pin_d4 = Y6_GPIO_NUM;
  config.pin_d5 = Y7_GPIO_NUM;
  config.pin_d6 = Y8_GPIO_NUM;
  config.pin_d7 = Y9_GPIO_NUM;
  config.pin_xclk = XCLK_GPIO_NUM;
  config.pin_pclk = PCLK_GPIO_NUM;
  config.pin_vsync = VSYNC_GPIO_NUM;
  config.pin_href = HREF_GPIO_NUM;
  config.pin_sccb_sda = SIOD_GPIO_NUM;
  config.pin_sccb_scl = SIOC_GPIO_NUM;
  config.pin_pwdn = PWDN_GPIO_NUM;
  config.pin_reset = RESET_GPIO_NUM;
  config.xclk_freq_hz = 20000000;
  config.frame_size = FRAMESIZE_QVGA;
  config.pixel_format = PIXFORMAT_JPEG;
  config.grab_mode = CAMERA_GRAB_LATEST;
  config.fb_location = CAMERA_FB_IN_PSRAM;
  config.jpeg_quality = 12;
  config.fb_count = psramFound() ? 2 : 1;

  if (!psramFound()) {
    Serial.println("Warning: PSRAM not found, using DRAM framebuffer.");
    config.fb_location = CAMERA_FB_IN_DRAM;
  }

  const esp_err_t err = esp_camera_init(&config);
  if (err != ESP_OK) {
    Serial.printf("Camera init failed: 0x%x\n", err);
    return false;
  }

  sensor_t *sensor = esp_camera_sensor_get();
  if (sensor != nullptr) {
    if (sensor->id.PID == OV3660_PID) {
      sensor->set_vflip(sensor, 1);
      sensor->set_brightness(sensor, 1);
      sensor->set_saturation(sensor, -2);
    }
    sensor->set_framesize(sensor, FRAMESIZE_QVGA);
  }

  return true;
}

bool connectWiFi() {
  WiFi.mode(WIFI_STA);
  WiFi.setSleep(false);

  if (!WiFi.config(LOCAL_IP, GATEWAY, SUBNET, DNS_SERVER)) {
    Serial.println("Warning: failed to apply static IP configuration.");
  }

  WiFi.begin(WIFI_SSID, WIFI_PASSWORD);
  Serial.printf("Connecting QR reader to SSID: %s", WIFI_SSID);

  const unsigned long startMs = millis();
  while (WiFi.status() != WL_CONNECTED && millis() - startMs < 20000) {
    delay(500);
    Serial.print(".");
  }
  Serial.println();

  if (WiFi.status() == WL_CONNECTED) {
    Serial.printf("QR reader IP: %s\n", WiFi.localIP().toString().c_str());
    Serial.printf("RSSI: %d dBm\n", WiFi.RSSI());
    return true;
  }

  Serial.println("QR reader failed to connect to FrontCam AP.");
  return false;
}

void ensureWiFiConnection() {
  if (WiFi.status() == WL_CONNECTED) {
    return;
  }

  const unsigned long now = millis();
  if (now - lastReconnectAttemptMs < WIFI_RECONNECT_INTERVAL_MS) {
    return;
  }

  lastReconnectAttemptMs = now;
  Serial.println("Wi-Fi disconnected. Reconnecting QR reader...");
  WiFi.disconnect();
  connectWiFi();
}

static esp_err_t streamHandler(httpd_req_t *req) {
  static const char *STREAM_CONTENT_TYPE = "multipart/x-mixed-replace;boundary=frame";
  static const char *STREAM_BOUNDARY = "\r\n--frame\r\n";
  static const char *STREAM_PART = "Content-Type: image/jpeg\r\nContent-Length: %u\r\n\r\n";

  esp_err_t res = httpd_resp_set_type(req, STREAM_CONTENT_TYPE);
  if (res != ESP_OK) {
    return res;
  }
  httpd_resp_set_hdr(req, "Access-Control-Allow-Origin", "*");
  httpd_resp_set_hdr(req, "Cache-Control", "no-store");

  while (true) {
    camera_fb_t *fb = esp_camera_fb_get();
    if (fb == nullptr) {
      Serial.println("Camera frame capture failed");
      return ESP_FAIL;
    }

    char partBuffer[64];
    const size_t headerLength = snprintf(partBuffer, sizeof(partBuffer), STREAM_PART, fb->len);

    res = httpd_resp_send_chunk(req, STREAM_BOUNDARY, strlen(STREAM_BOUNDARY));
    if (res == ESP_OK) {
      res = httpd_resp_send_chunk(req, partBuffer, headerLength);
    }
    if (res == ESP_OK) {
      res = httpd_resp_send_chunk(req, reinterpret_cast<const char *>(fb->buf), fb->len);
    }

    esp_camera_fb_return(fb);

    if (res != ESP_OK) {
      break;
    }

    vTaskDelay(pdMS_TO_TICKS(45));
  }

  return res;
}

void startStreamServer() {
  httpd_config_t config = HTTPD_DEFAULT_CONFIG();
  config.server_port = STREAM_PORT;
  config.ctrl_port = 32770;

  const httpd_uri_t streamUri = {
      .uri = "/stream",
      .method = HTTP_GET,
      .handler = streamHandler,
      .user_ctx = nullptr,
  };

  if (httpd_start(&streamHttpd, &config) == ESP_OK) {
    httpd_register_uri_handler(streamHttpd, &streamUri);
    Serial.printf("QR stream ready on port %u\n", STREAM_PORT);
  } else {
    Serial.println("Failed to start QR stream server");
  }
}

String distanceJson() {
  updateDistanceSensor(true);
  String json = "{";
  json += "\"online\":" + String(distanceReading.online ? "true" : "false") + ",";
  json += "\"mm\":" + String(distanceReading.mm, 1) + ",";
  json += "\"cm\":" + String(distanceReading.mm / 10.0f, 1) + ",";
  json += "\"in_range\":" + String(distanceReading.inRange ? "true" : "false") + ",";
  json += "\"read_count\":" + String(distanceReading.readCount) + ",";
  json += "\"error\":\"" + jsonEscape(distanceReading.error) + "\"";
  json += "}";
  return json;
}

String motorJson() {
  String json = "{";
  json += "\"outputs_enabled\":" + String(MOTOR_OUTPUTS_ENABLED ? "true" : "false") + ",";
  json += "\"last_command\":\"" + jsonEscape(lastMotorCommand) + "\",";
  json += "\"left_speed\":" + String(lastLeftSpeed) + ",";
  json += "\"right_speed\":" + String(lastRightSpeed) + ",";
  json += "\"command_count\":" + String(commandCount) + ",";
  json += "\"phase\":\"" + String(phaseName(plan.phase)) + "\",";
  json += "\"turn_ms\":" + String(plan.turnMs) + ",";
  json += "\"drive_ms\":" + String(plan.driveMs) + ",";
  json += "\"speed\":" + String(plan.speed) + ",";
  json += "\"last_error\":\"" + jsonEscape(plan.lastError) + "\"";
  json += "}";
  return json;
}

void handleRoot() {
  requestCount++;
  addCorsHeaders();
  web.send_P(200, "text/html", INDEX_HTML);
}

void handleStatus() {
  requestCount++;
  addCorsHeaders();

  String json = "{";
  json += "\"status\":\"ok\",";
  json += "\"role\":\"qr_reader_robot\",";
  json += "\"wifi_connected\":" + String(WiFi.status() == WL_CONNECTED ? "true" : "false") + ",";
  json += "\"ip\":\"" + WiFi.localIP().toString() + "\",";
  json += "\"stream_url\":\"http://" + WiFi.localIP().toString() + ":" + String(STREAM_PORT) + "/stream\",";
  json += "\"rssi\":" + String(WiFi.RSSI()) + ",";
  json += "\"request_count\":" + String(requestCount) + ",";
  json += "\"motor\":" + motorJson() + ",";
  json += "\"distance\":" + distanceJson() + ",";
  json += "\"last_qr_id\":\"" + jsonEscape(lastQrId) + "\",";
  json += "\"qr_count\":" + String(qrCount);
  json += "}";

  web.send(200, "application/json", json);
}

void handleDistance() {
  requestCount++;
  addCorsHeaders();
  web.send(200, "application/json", distanceJson());
}

void handleCapture() {
  requestCount++;

  camera_fb_t *fb = esp_camera_fb_get();
  if (fb == nullptr) {
    addCorsHeaders();
    web.send(503, "application/json", "{\"status\":\"error\",\"error\":\"Camera capture failed\"}");
    return;
  }

  web.sendHeader("Access-Control-Allow-Origin", "*");
  web.sendHeader("Cache-Control", "no-store");
  web.setContentLength(fb->len);
  web.send(200, "image/jpeg", "");
  WiFiClient client = web.client();
  client.write(fb->buf, fb->len);
  esp_camera_fb_return(fb);
}
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
void loop() {
  ensureWiFiConnection();
  web.handleClient();
  updateMotionPlan();
  updateDistanceSensor();
  delay(2);
}

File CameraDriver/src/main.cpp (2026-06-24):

#include <Arduino.h>
#include <DNSServer.h>
#include <WebServer.h>
#include <WiFi.h>
#include <Wire.h>
#include "esp_camera.h"

// DFRobot TB6612FNG 2x1.2A motor driver on XIAO Arduino pins.
const int LEFT_DIR_PIN = D7;    // DIR1
const int LEFT_PWM_PIN = D8;    // PWM1
const int RIGHT_DIR_PIN = D10;  // DIR2
const int RIGHT_PWM_PIN = D9;   // PWM2
const int LEFT_PWM_CHANNEL = 2;
const int RIGHT_PWM_CHANNEL = 3;
const int MOTOR_PWM_FREQ = 20000;
const int MOTOR_PWM_RESOLUTION = 8;
const int MOTOR_SPEED = 220;  // 0-255

const int STATUS_LED = LED_BUILTIN;
const int I2C_SDA_PIN = 5;  // XIAO D4
const int I2C_SCL_PIN = 6;  // XIAO D5
const uint8_t COLOR_SENSOR_ADDR = 0x29;
const unsigned long COLOR_READ_INTERVAL_MS = 250;

const uint8_t TCS_COMMAND_BIT = 0x80;
const uint8_t TCS_ENABLE = 0x00;
const uint8_t TCS_ATIME = 0x01;
const uint8_t TCS_CONTROL = 0x0F;
const uint8_t TCS_ID = 0x12;
const uint8_t TCS_STATUS = 0x13;
const uint8_t TCS_CDATAL = 0x14;
const uint8_t TCS_RDATAL = 0x16;
const uint8_t TCS_GDATAL = 0x18;
const uint8_t TCS_BDATAL = 0x1A;
const uint8_t TCS_ENABLE_PON = 0x01;
const uint8_t TCS_ENABLE_AEN = 0x02;
const uint8_t TCS_STATUS_AVALID = 0x01;
const uint8_t TCS_INTEGRATIONTIME_154MS = 0xC0;
const uint8_t TCS_GAIN_4X = 0x01;

const char *SETUP_AP_SSID = "CameraDriver-Setup";
const char *SETUP_AP_PASSWORD = "smars1234";
const char *LOCAL_DNS_NAME = "narbot.esp";
const byte DNS_PORT = 53;
const unsigned long STREAM_FRAME_INTERVAL_MS = 120;

// Seeed Studio XIAO ESP32S3 Sense camera pins.
const int CAM_PIN_PWDN = -1;
const int CAM_PIN_RESET = -1;
const int CAM_PIN_XCLK = 10;
const int CAM_PIN_SIOD = 40;
const int CAM_PIN_SIOC = 39;
const int CAM_PIN_Y9 = 48;
const int CAM_PIN_Y8 = 11;
const int CAM_PIN_Y7 = 12;
const int CAM_PIN_Y6 = 14;
const int CAM_PIN_Y5 = 16;
const int CAM_PIN_Y4 = 18;
const int CAM_PIN_Y3 = 17;
const int CAM_PIN_Y2 = 15;
const int CAM_PIN_VSYNC = 38;
const int CAM_PIN_HREF = 47;
const int CAM_PIN_PCLK = 13;

struct LedPatternStep {
  bool on;
  unsigned long durationMs;
};

struct LedPattern {
  const LedPatternStep *steps;
  size_t stepCount;
};

struct ColorReading {
  bool available;
  uint16_t clear;
  uint16_t red;
  uint16_t green;
  uint16_t blue;
  uint8_t displayRed;
  uint8_t displayGreen;
  uint8_t displayBlue;
};

enum SerialConsoleMode {
  SERIAL_CONSOLE_MAIN,
  SERIAL_CONSOLE_DRIVE,
  SERIAL_CONSOLE_WIFI,
};

enum MotorDirection {
  MOTOR_STOPPED,
  MOTOR_FORWARD,
  MOTOR_BACKWARD,
};

const LedPatternStep STOP_LED_STEPS[] = {
    {true, 50},
    {false, 1950},
};

const LedPatternStep FORWARD_LED_STEPS[] = {
    {true, 40},
    {false, 210},
};

const LedPatternStep BACKWARD_LED_STEPS[] = {
    {true, 70},
    {false, 120},
    {true, 70},
    {false, 740},
};

const LedPatternStep LEFT_LED_STEPS[] = {
    {true, 250},
    {false, 750},
};

const LedPatternStep RIGHT_LED_STEPS[] = {
    {true, 60},
    {false, 120},
    {true, 60},
    {false, 120},
    {true, 60},
    {false, 580},
};

const LedPattern STOP_LED_PATTERN = {STOP_LED_STEPS, 2};
const LedPattern FORWARD_LED_PATTERN = {FORWARD_LED_STEPS, 2};
const LedPattern BACKWARD_LED_PATTERN = {BACKWARD_LED_STEPS, 4};
const LedPattern LEFT_LED_PATTERN = {LEFT_LED_STEPS, 2};
const LedPattern RIGHT_LED_PATTERN = {RIGHT_LED_STEPS, 6};

const LedPattern *currentLedPattern = &STOP_LED_PATTERN;
size_t currentLedStep = 0;
unsigned long ledStepStartedAt = 0;
bool cameraReady = false;
bool webServerStarted = false;
bool restartRequested = false;
unsigned long restartAt = 0;
bool headlightsEnabled = false;
MotorDirection leftMotorState = MOTOR_STOPPED;
MotorDirection rightMotorState = MOTOR_STOPPED;
int leftMotorPwm = 0;
int rightMotorPwm = 0;
bool colorSensorReady = false;
uint8_t colorSensorId = 0;
ColorReading latestColor = {};
unsigned long lastColorReadAt = 0;
String serialLine;
SerialConsoleMode serialMode = SERIAL_CONSOLE_MAIN;

WebServer server(80);
DNSServer dnsServer;
WiFiServer streamServer(81);
WiFiClient streamClient;
unsigned long lastStreamFrameAt = 0;

void stopMotors();
void driveForward();
void driveBackward();
void turnLeft();
void turnRight();
void testLeftForward();
void testLeftBackward();
void testRightForward();
void testRightBackward();
void setStatusLedPattern(const LedPattern &pattern);
void updateStatusLed();
void writeStatusLed(bool on);
void setHeadlights(bool enabled);
void handleSerialCommand(char cmd);
void printCommandHelp();
void printMainHelp();
void printDriveHelp();
void initCamera();
void initColorSensor();
void updateColorSensor();
bool readColorSensor(ColorReading &reading);
void normalizeColorReading(ColorReading &reading);
void handleColorState();
bool writeColorRegister(uint8_t reg, uint8_t value);
bool readColorRegister(uint8_t reg, uint8_t &value);
bool readColorRegister16(uint8_t reg, uint16_t &value);
void captureAndSendImage();
camera_fb_t *captureFreshFrame();
void handleSerialInput();
void handleSerialLine(const String &line);
void handleMainSerialLine(const String &command);
void handleDriveSerialLine(const String &command);
void handleWifiSerialLine(const String &command);
void printWifiHelp();
void scanWifiNetworks();
void startSetupAccessPoint();
void startLocalDns();
void startWebServer();
void startStreamServer();
void updateStreamServer();
void sendStreamHeaders(WiFiClient &client);
void sendStreamFrame(WiFiClient &client);
void handleRoot();
void handleWifiSetupPage();
void handleWifiSave();
void handleWebCapture();
void handleMotorState();
void sendPlainText(const String &message);
void printNetworkStatus();
void requestRestart();
void setMotorState(MotorDirection leftDirection, MotorDirection rightDirection);
void writeMotor(int dirPin, int pwmChannel, MotorDirection direction, int speed);
const char *motorDirectionName(MotorDirection direction);
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

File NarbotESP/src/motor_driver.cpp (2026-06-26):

#include "motor_driver.h"

#include <Arduino.h>

#include "obstacle_safety.h"

namespace {

#ifdef MAIN_ESP
// DFRobot TB6612FNG motor driver on Seeed XIAO ESP32S3 Arduino pins.
constexpr int LEFT_DIR_PIN = D6;   // GPIO43, DIR1
constexpr int LEFT_PWM_PIN = D5;   // GPIO6, PWM1
constexpr int RIGHT_DIR_PIN = D4;  // GPIO5, DIR2
constexpr int RIGHT_PWM_PIN = D3;  // GPIO4, PWM2

constexpr int LEFT_PWM_CHANNEL = 2;
constexpr int RIGHT_PWM_CHANNEL = 3;
constexpr int MOTOR_PWM_FREQ = 20000;
constexpr int MOTOR_PWM_RESOLUTION = 8;
constexpr int DEFAULT_MOTOR_SPEED = 180;
constexpr int MAX_MOTOR_SPEED = 255;
constexpr int MOTOR_RAMP_STEP = 12;
constexpr unsigned long MOTOR_RAMP_INTERVAL_MS = 30;
#else
constexpr int DEFAULT_MOTOR_SPEED = 0;
constexpr int MAX_MOTOR_SPEED = 0;
#endif

MotorDirection leftDirection = MotorDirection::Stopped;
MotorDirection rightDirection = MotorDirection::Stopped;
int leftPwm = 0;
int rightPwm = 0;
int leftTargetPwm = 0;
int rightTargetPwm = 0;
int targetSpeed = DEFAULT_MOTOR_SPEED;
unsigned long lastRampAt = 0;

#ifdef MAIN_ESP
void writeMotor(int dirPin, int pwmChannel, MotorDirection direction, int speed) {
  digitalWrite(dirPin, direction == MotorDirection::Backward ? HIGH : LOW);
  ledcWrite(pwmChannel, speed);
}

int stepToward(int value, int target) {
  if (value < target) {
    return min(value + MOTOR_RAMP_STEP, target);
  }

  if (value > target) {
    return max(value - MOTOR_RAMP_STEP, target);
  }

  return value;
}
#endif

void setMotorState(MotorDirection newLeftDirection, MotorDirection newRightDirection) {
  bool leftDirectionChanged = leftDirection != newLeftDirection;
  bool rightDirectionChanged = rightDirection != newRightDirection;

  leftDirection = newLeftDirection;
  rightDirection = newRightDirection;
  leftTargetPwm = leftDirection == MotorDirection::Stopped ? 0 : targetSpeed;
  rightTargetPwm = rightDirection == MotorDirection::Stopped ? 0 : targetSpeed;

  if (leftDirection == MotorDirection::Stopped || leftDirectionChanged) {
    leftPwm = 0;
  }

  if (rightDirection == MotorDirection::Stopped || rightDirectionChanged) {
    rightPwm = 0;
  }

#ifdef MAIN_ESP
  writeMotor(LEFT_DIR_PIN, LEFT_PWM_CHANNEL, leftDirection, leftPwm);
  writeMotor(RIGHT_DIR_PIN, RIGHT_PWM_CHANNEL, rightDirection, rightPwm);
  Serial.printf("Motor target: left=%s pwm=%d right=%s pwm=%d speed=%d\n",
                motorDirectionName(leftDirection),
                leftTargetPwm,
                motorDirectionName(rightDirection),
                rightTargetPwm,
                targetSpeed);
#endif
}

}  // namespace

void setupMotorDriver() {
#ifdef MAIN_ESP
  pinMode(LEFT_PWM_PIN, OUTPUT);
  pinMode(RIGHT_PWM_PIN, OUTPUT);
  pinMode(LEFT_DIR_PIN, OUTPUT);
  pinMode(RIGHT_DIR_PIN, OUTPUT);

  digitalWrite(LEFT_PWM_PIN, LOW);
  digitalWrite(RIGHT_PWM_PIN, LOW);
  digitalWrite(LEFT_DIR_PIN, LOW);
  digitalWrite(RIGHT_DIR_PIN, LOW);

  ledcSetup(LEFT_PWM_CHANNEL, MOTOR_PWM_FREQ, MOTOR_PWM_RESOLUTION);
  ledcSetup(RIGHT_PWM_CHANNEL, MOTOR_PWM_FREQ, MOTOR_PWM_RESOLUTION);
  ledcWrite(LEFT_PWM_CHANNEL, 0);
  ledcWrite(RIGHT_PWM_CHANNEL, 0);
  ledcAttachPin(LEFT_PWM_PIN, LEFT_PWM_CHANNEL);
  ledcAttachPin(RIGHT_PWM_PIN, RIGHT_PWM_CHANNEL);
#endif

  stopMotors();

#ifdef MAIN_ESP
  Serial.println("Motor driver initialized");
  Serial.printf("Left motor: DIR D6/GPIO%d, PWM D5/GPIO%d, LEDC channel %d\n", LEFT_DIR_PIN, LEFT_PWM_PIN, LEFT_PWM_CHANNEL);
  Serial.printf("Right motor: DIR D4/GPIO%d, PWM D3/GPIO%d, LEDC channel %d\n", RIGHT_DIR_PIN, RIGHT_PWM_PIN, RIGHT_PWM_CHANNEL);
#endif
}

void handleMotorDriver() {
#ifdef MAIN_ESP
  if (millis() - lastRampAt < MOTOR_RAMP_INTERVAL_MS) {
    return;
  }

  lastRampAt = millis();
  int nextLeftPwm = stepToward(leftPwm, leftTargetPwm);
  int nextRightPwm = stepToward(rightPwm, rightTargetPwm);

  if (nextLeftPwm == leftPwm && nextRightPwm == rightPwm) {
    return;
  }

  leftPwm = nextLeftPwm;
  rightPwm = nextRightPwm;
  writeMotor(LEFT_DIR_PIN, LEFT_PWM_CHANNEL, leftDirection, leftPwm);
  writeMotor(RIGHT_DIR_PIN, RIGHT_PWM_CHANNEL, rightDirection, rightPwm);
#endif
}

void stopMotors() {
  setMotorState(MotorDirection::Stopped, MotorDirection::Stopped);
}

void driveForward() {
  if (isForwardBlocked()) {
    Serial.println("Forward blocked by obstacle safety");
    stopMotors();
    return;
  }

  setMotorState(MotorDirection::Forward, MotorDirection::Forward);
}

void driveBackward() {
  setMotorState(MotorDirection::Backward, MotorDirection::Backward);
}

void turnLeft() {
  setMotorState(MotorDirection::Backward, MotorDirection::Forward);
}
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

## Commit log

2026-06-24 Add cad
    [stl_kere2.stl, stl_lyli.stl, stl_ratas_sisemine.step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]
2026-06-26 Fix design
    [stl_kere2.stl]
2026-06-26 Motor dirver
2026-06-28 Fix kere2 cutouts
    [stl_kere2.stl]
2026-06-29 Update KiCad project
    [NarbotPCB.kicad_pcb, NarbotPCB.kicad_sch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]
